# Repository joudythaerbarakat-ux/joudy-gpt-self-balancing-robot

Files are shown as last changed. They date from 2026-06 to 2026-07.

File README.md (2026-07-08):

# Joudy GPT — Self-Balancing Robot with BLE Control Interface

> **Presented at NICE 2026** — 11th National Innovation Competition in Engineering  
> Tishk International University, Erbil, Iraq | Dean's Certificate of Appreciation awarded

Demo

---

## Overview

A two-wheeled self-balancing robot implementing a **Kalman-filtered PID controller** on ESP32, with a custom **Bluetooth web app** for real-time control and a **7-state animated LCD emotion display**.

Built and presented at the National Innovation Competition in Engineering (NICE 2026), Mechatronics Department (MECHAT 4), Tishk International University.

---

## Key Technical Features

- **Kalman Filter + PID** — sensor fusion of MPU6050 accelerometer and gyroscope for stable angle estimation; balance loop running at ~100 Hz
- **Dual operating modes** — RC mode (manual BLE control) and BALANCE mode (autonomous stabilisation with BLE directional trim)
- **Live PID tuning over BLE** — Kp, Ki, Kd, setpoint, and axis configuration adjustable at runtime without re-flashing firmware
- **7-state animated LCD face system** — IDLE (auto-blink), HAPPY, SAD, ANGRY, SURPRISED, TALKING (mouth animation), THINKING (asymmetric eye animation); all BLE-controllable in real time
- **Custom BLE web app** — HTML/CSS/JavaScript using Web Bluetooth API; D-pad control, 3 speed modes, 5 pre-programmed voice lines via browser Web Speech API

---

## Hardware

| Component | Role |
|---|---|
| ESP32 WROOM-32 | Main MCU, BLE host |
| MPU6050 IMU | 6-axis accelerometer + gyroscope |
| L298N Motor Driver | Dual DC motor PWM control |
| DC Geared Motors ×2 | Drive wheels |
| XL4015 Buck Converter | 14.8V → 5V power regulation |
| 4× 18650 Li-ion (14.8V, 4S) | Main power supply |
| LCD 16×2 I²C (0x27) | Animated emotion face display |
| PETG 3D-printed chassis | Custom SolidWorks design |

---

## Wiring Diagram

Wiring Diagram

> ⚠️ Diagram is illustrative. Exact GPIO assignments are defined in `AI_ROBOT.ino` (lines 14–19).  
> Motor pins: IN1=14, IN2=27, ENA=12, IN3=13, IN4=15, ENB=33. I²C: SDA=21, SCL=22.

---

## Software Architecture

```
loop() ~100 Hz
├── handleSerialCommands()     # BLE + Serial command parser
├── balanceUpdate(dt)          # Core balance loop
│   ├── mpuRead()              # Raw IMU register read (I²C)
│   ├── getRawAccelAngle()     # atan2 angle from accel axes
│   ├── getRawGyroRate()       # Gyro rate with axis selection
│   ├── kalman.update()        # Discrete Kalman filter
│   └── motorsDriveRaw()       # L298N PWM output with deadband
└── updateFace()               # LCD state machine @ 10 Hz
```

---

## Control System

Discrete Kalman filter for angle estimation, fusing accelerometer (absolute angle) and gyroscope (rate integration):

| Parameter | Value |
|---|---|
| Process noise Q_angle | 0.001 |
| Process noise Q_bias | 0.003 |
| Measurement noise R_meas | 0.03 |
| Default Kp | 12.0 |
| Default Ki | 0.0 |
| Default Kd | 0.8 |
| Safety tilt cutout | ±35° |
| Integral windup limit | ±80 |
| Target loop rate | ~100 Hz |

---

## BLE Command Reference

| Command | Action |
|---|---|
| `F` / `B` / `L` / `R` / `S` | Move / Stop |
| `MODE:RC` | Manual remote control mode |
| `MODE:BALANCE` | Autonomous self-balance mode |
| `CAL` | Calibrate upright angle (300-sample average) |
| `KP:12.0` / `KI:0.0` / `KD:0.8` | Live PID tuning |
| `SP:0.0` | Adjust balance setpoint angle |
| `AXIS:X` / `AXIS:Y` | Select accelerometer tilt axis |
| `GYRO:X/Y/Z` | Select gyroscope rate axis |
| `INV:0` / `INV:1` | Invert angle sign |
| `MINPWM:80` | Motor deadband compensation |
| `DIAG:1` / `DIAG:0` | Serial diagnostic output |
| `FACE:HAPPY` etc. | Set LCD emotion |
| `SPD:1/2/3` | Set RC speed level |

---

## Repository Structure

```
joudy-gpt-self-balancing-robot/
├── AI_ROBOT.ino          # Main ESP32 firmware
├── web-app/
│   └── index.html        # BLE controller (open in Chrome on Android)
├── docs/
│   ├── demo.gif          # Live demonstration
│   └── wiring-diagram.png
├── cad/                  # SolidWorks chassis files 
└── README.md
```

---

## Build & Flash

**Requirements:**
- Arduino IDE 2.x with ESP32 Arduino Core 3.x
- Libraries: `LiquidCrystal_I2C`, `BLEDevice` (ESP32 built-in)

**Steps:**
1. Open `AI_ROBOT.ino` in Arduino IDE
2. Select board: `ESP32 Dev Module`
3. Flash at 115200 baud
4. Open Serial Monitor → send `HELP` for full command reference
5. Open `web-app/index.html` in **Chrome on Android** → tap Connect

---

## Calibration Procedure

1. Place robot on a flat surface, hold **upright and still**
2. Send `CAL` via BLE or Serial Monitor
3. Robot averages 300 samples over ~1.5 seconds
4. Send `MODE:BALANCE`
5. Trim `SP:` value (e.g. `SP:1.5`) to correct forward/backward lean

---

## Competition

Presented at **NICE 2026** (11th National Innovation Competition in Engineering),  
Mechatronics Department (MECHAT 4), Tishk International University, Erbil, Iraq.  
Theme: *Targeting Smart Sustainable Innovations.*  
**Certificate of Appreciation** awarded by the Dean of Engineering Faculty, TIU.

---

## Author

   **Joudy Thaer Barakat**
   Mechatronics Engineering Student, Tishk International University
   [LinkedIn](https://linkedin.com/in/joudy-barakat) · joudythaerbarakat@gmail.com

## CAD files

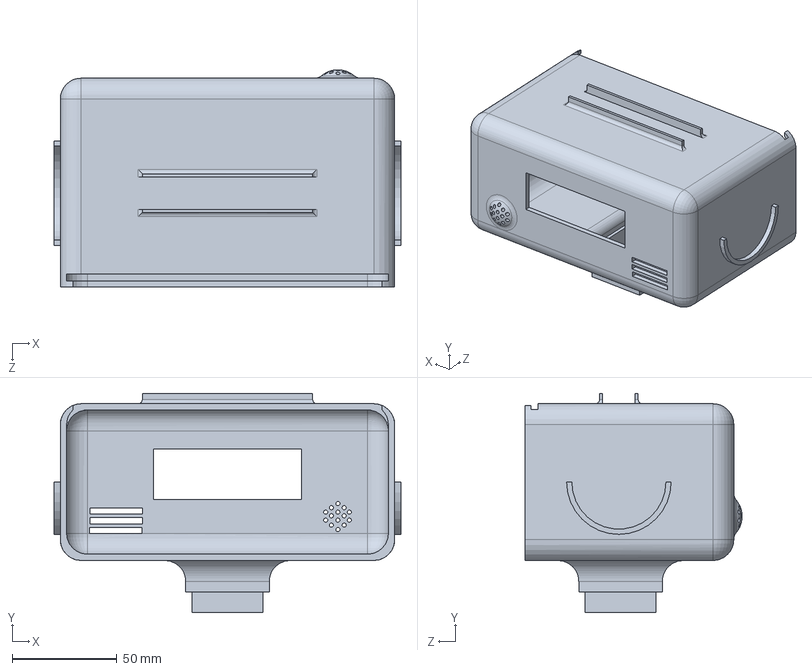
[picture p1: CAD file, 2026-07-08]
cad/head_assembly.SLDPRT
166.0 x 105.0 x 104.0 mm

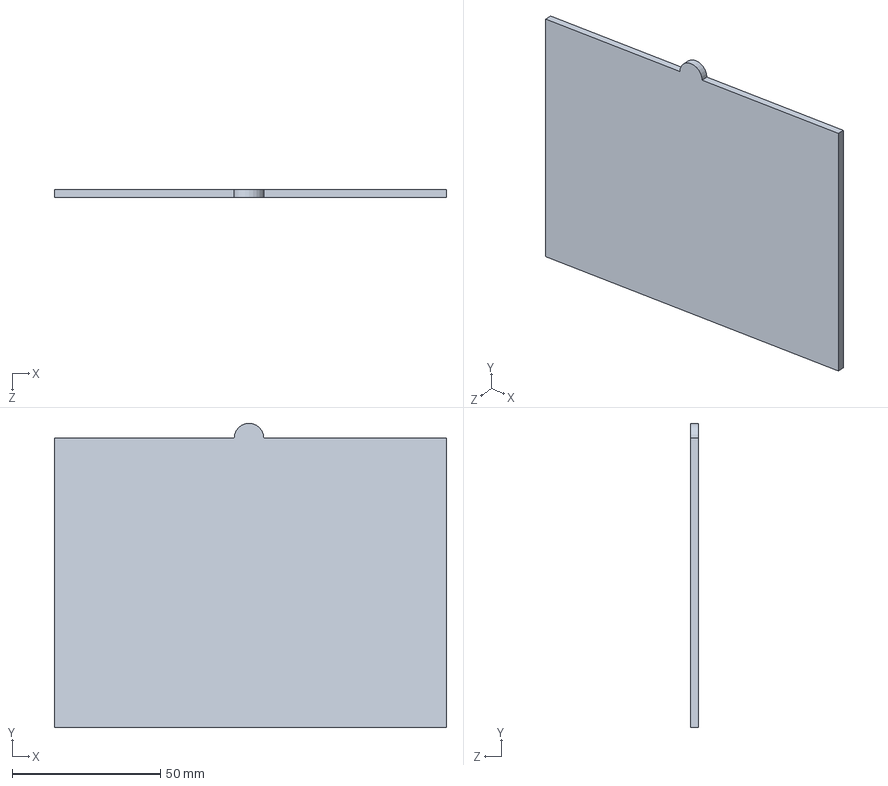
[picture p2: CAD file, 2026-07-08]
cad/door_1.SLDPRT
132.0 x 102.5 x 2.80 mm

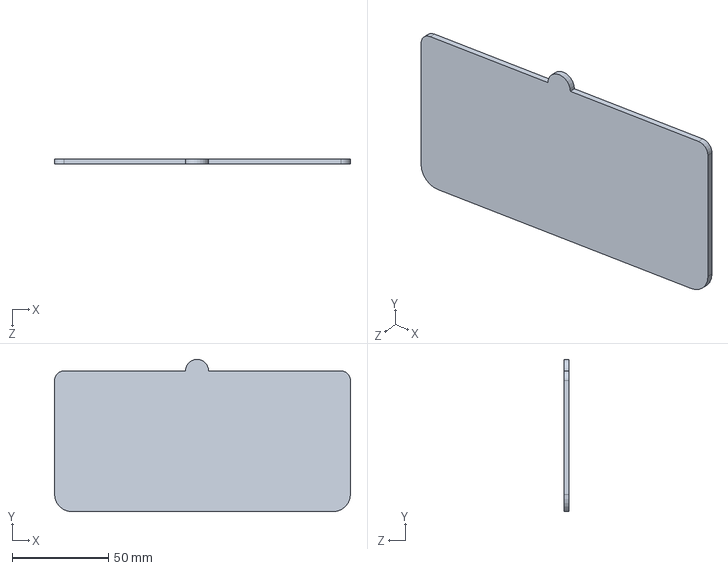
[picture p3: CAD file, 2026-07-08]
cad/door_2.SLDPRT
153.5 x 79.0 x 2.80 mm

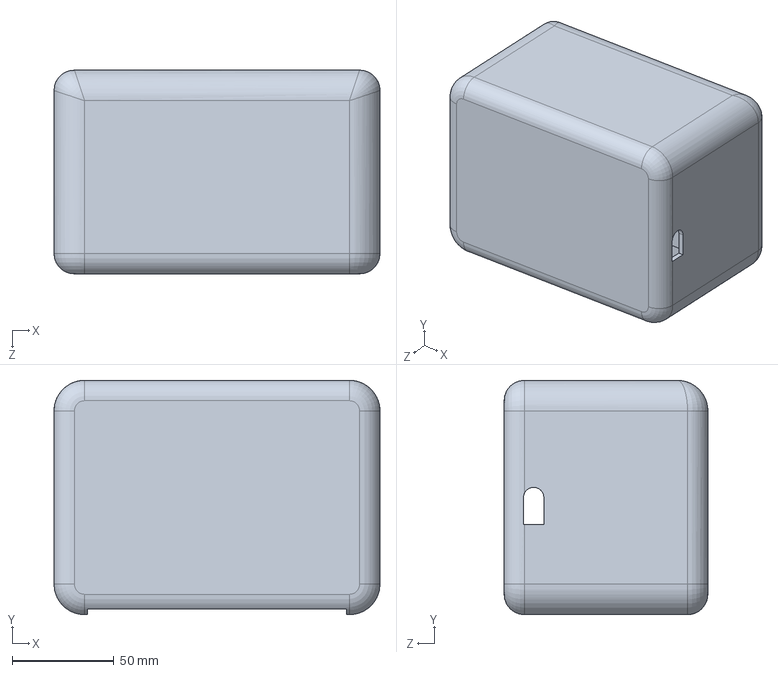
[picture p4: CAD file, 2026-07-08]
cad/chassis_body.SLDPRT
160.0 x 115.0 x 100.0 mm

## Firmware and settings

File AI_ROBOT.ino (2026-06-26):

/*
 * AI_ROBOT — ESP32 BLE/Serial RC + Self-Balance + MPU6050/MPU9250 + LCD Faces
 * ESP32 Arduino Core 3.x compatible
 *
 * Joudy GPT — Self-Balancing Robot
 * Presented at NICE 2026, Tishk International University
 *
 * Runtime tuning via BLE or Serial (no re-upload needed):
 * - MODE:RC / MODE:BALANCE
 * - CAL
 * - AXIS:X / AXIS:Y
 * - GYRO:X / GYRO:Y / GYRO:Z
 * - INV:0 / INV:1
 * - KP:12.0 / KI:0.0 / KD:0.8
 * - SP:0.0
 * - MINPWM:80
 * - DIAG:1 / DIAG:0
 *
 * RC commands: F, B, L, R, S
 * Face commands: FACE:IDLE/HAPPY/SAD/ANGRY/SURPRISED/TALKING/THINKING
 */

#include <Wire.h>
#include <LiquidCrystal_I2C.h>
#include <BLEDevice.h>
#include <BLEServer.h>
#include <BLEUtils.h>
#include <BLE2902.h>

// ─────────────────────────────────────────────────────────────
// BLE UUIDs
// ─────────────────────────────────────────────────────────────
#define SERVICE_UUID  "12345678-1234-1234-1234-123456789abc"
#define CHAR_UUID     "abcdefab-cdef-abcd-efab-cdefabcdefab"

// ─────────────────────────────────────────────────────────────
// MOTOR PINS — L298N
// ─────────────────────────────────────────────────────────────
#define MOTOR_A_IN1  14
#define MOTOR_A_IN2  27
#define MOTOR_A_ENA  12

#define MOTOR_B_IN3  13
#define MOTOR_B_IN4  15
#define MOTOR_B_ENB  33

// ─────────────────────────────────────────────────────────────
// PWM
// ─────────────────────────────────────────────────────────────
#define PWM_FREQ  1000
#define PWM_BITS  8

const uint8_t SPEED_TABLE[3] = {120, 185, 230};
uint8_t currentSpeed = SPEED_TABLE[1];
int MIN_MOTOR_PWM = 80;

// ─────────────────────────────────────────────────────────────
// LCD
// ─────────────────────────────────────────────────────────────
LiquidCrystal_I2C lcd(0x27, 16, 2);

// ─────────────────────────────────────────────────────────────
// MPU
// ─────────────────────────────────────────────────────────────
#define MPU_ADDR 0x68

// ─────────────────────────────────────────────────────────────
// ROBOT MODE
// ─────────────────────────────────────────────────────────────
enum RobotMode { MODE_RC, MODE_BALANCE };
RobotMode robotMode = MODE_RC;

enum TiltAxis { TILT_X, TILT_Y };
enum GyroAxis { GYRO_X, GYRO_Y, GYRO_Z };

TiltAxis tiltAxis = TILT_X;
GyroAxis gyroAxis = GYRO_X;

bool invertAngle   = false;
bool diagnosticMode = true;

// ─────────────────────────────────────────────────────────────
// KALMAN FILTER
// ─────────────────────────────────────────────────────────────
struct Kalman {
  float angle = 0.0f;
  float bias  = 0.0f;
  float P[2][2] = {{1,0},{0,1}};

  const float Q_angle = 0.001f;
  const float Q_bias  = 0.003f;
  const float R_meas  = 0.03f;

  float update(float newAngle, float newRate, float dt) {
    angle += dt * (newRate - bias);
    P[0][0] += dt * (dt*P[1][1] - P[0][1] - P[1][0] + Q_angle);
    P[0][1] -= dt * P[1][1];
    P[1][0] -= dt * P[1][1];
    P[1][1] += Q_bias * dt;

    float S  = P[0][0] + R_meas;
    float K0 = P[0][0] / S;
    float K1 = P[1][0] / S;
    float y  = newAngle - angle;

    angle += K0 * y;
    bias  += K1 * y;

    float P00t = P[0][0], P01t = P[0][1];
    P[0][0] -= K0 * P00t;
    P[0][1] -= K0 * P01t;
    P[1][0] -= K1 * P00t;
    P[1][1] -= K1 * P01t;

    return angle;
  }

  void reset(float startAngle = 0.0f) {
    angle = startAngle; bias = 0.0f;
    P[0][0]=1; P[0][1]=0; P[1][0]=0; P[1][1]=1;
  }
};

Kalman kalman;

// ─────────────────────────────────────────────────────────────
// PID
// ─────────────────────────────────────────────────────────────
float Kp = 12.0f, Ki = 0.0f, Kd = 0.8f;
float angle_setpoint = 0.0f, base_setpoint = 0.0f;
float integral = 0.0f, prev_error = 0.0f;
float accelAngleOffset = 0.0f, gyroOffset = 0.0f;

const float INTEGRAL_LIMIT = 80.0f;
const float TILT_CUTOUT    = 35.0f;

bool calibrated = false;

float balanceDriveTrim = 0.0f;
int   balanceTurnTrim  = 0;

const float BALANCE_FORWARD_SP  =  2.0f;
const float BALANCE_BACKWARD_SP = -2.0f;
const int   BALANCE_TURN_PWM    =  35;

// ─────────────────────────────────────────────────────────────
// DEBUG
// ─────────────────────────────────────────────────────────────
unsigned long lastDebugMs = 0;
const int DEBUG_INTERVAL  = 150;

// ─────────────────────────────────────────────────────────────
// BLE
// ─────────────────────────────────────────────────────────────
bool deviceConnected = false;
BLECharacteristic* pCharacteristic = nullptr;

// ─────────────────────────────────────────────────────────────
// LCD FACE
// ─────────────────────────────────────────────────────────────
enum FaceState { IDLE, HAPPY, SAD, ANGRY, SURPRISED, TALKING, THINKING };
FaceState currentFace = IDLE, pendingFace = IDLE;
bool faceChanged = false;

#define C_EYE_OPEN   0
#define C_EYE_HALF   1
#define C_EYE_SHUT   2
#define C_M_HAPPY    3
#define C_M_SAD      4
#define C_M_TALK     5
#define C_M_FLAT     6
#define C_EYEBROW_UP 7

byte EYES_OPEN[8]    = {0b00000,0b01110,0b11111,0b11011,0b11111,0b01110,0b00000,0b00000};
byte EYES_HALF[8]    = {0b00000,0b00000,0b01110,0b11111,0b11111,0b01110,0b00000,0b00000};
byte EYES_SHUT[8]    = {0b00000,0b00000,0b00000,0b11111,0b00000,0b00000,0b00000,0b00000};
byte MOUTH_HAPPY[8]  = {0b00000,0b00000,0b10001,0b01110,0b00000,0b00000,0b00000,0b00000};
byte MOUTH_SAD[8]    = {0b00000,0b00000,0b01110,0b10001,0b00000,0b00000,0b00000,0b00000};
byte MOUTH_TALK[8]   = {0b00000,0b01110,0b11111,0b01110,0b00000,0b00000,0b00000,0b00000};
byte MOUTH_FLAT[8]   = {0b00000,0b00000,0b11111,0b00000,0b00000,0b00000,0b00000,0b00000};
byte EYEBROW_UP[8]   = {0b11111,0b00000,0b01110,0b11111,0b11011,0b11111,0b01110,0b00000};

struct FaceBuffer { byte left,right,mouth; bool browLeft,browRight; };
FaceBuffer displayedFace = {255,255,255,false,false};

// ─────────────────────────────────────────────────────────────
// FORWARD DECLARATIONS
// ─────────────────────────────────────────────────────────────
void handleCommand(String cmd);
void handleSerialCommands();
void motorsStop();
void motorsDriveRaw(int l, int r);
void motorsDrive(int pwm, bool lf, bool rf);
void motorsTurn(bool spinRight);
bool mpuInit();
void mpuRead(float&,float&,float&,float&,float&,float&);
float getRawAccelAngle(float,float,float);
float getRawGyroRate(float,float,float);
void calibrateMPU();
void balanceUpdate(float dt);
void setupLCDChars();
void lcdClearFace();
void updateFace();
void renderFace(byte,byte,byte,bool,bool);
void notifyText(const String&);

// ─────────────────────────────────────────────────────────────
// BLE CALLBACKS
// ─────────────────────────────────────────────────────────────
class ServerCallbacks : public BLEServerCallbacks {
  void onConnect(BLEServer*)    override { deviceConnected = true;  Serial.println("[BLE] Connected"); }
  void onDisconnect(BLEServer*) override {
    deviceConnected = false; motorsStop();
    robotMode = MODE_RC; balanceDriveTrim = 0; balanceTurnTrim = 0;
    Serial.println("[BLE] Disconnected");
    BLEDevice::startAdvertising();
  }
};

class CharCallbacks : public BLECharacteristicCallbacks {
  void onWrite(BLECharacteristic* c) override {
    String cmd = c->getValue().c_str();
    cmd.trim(); handleCommand(cmd);
  }
};

// ─────────────────────────────────────────────────────────────
// NOTIFY
// ─────────────────────────────────────────────────────────────
void notifyText(const String &msg) {
  Serial.println(msg);
  if (deviceConnected && pCharacteristic) {
    pCharacteristic->setValue(msg.c_str());
    pCharacteristic->notify();
  }
}

// ─────────────────────────────────────────────────────────────
// MPU
// ─────────────────────────────────────────────────────────────
bool mpuInit() {
  Wire.beginTransmission(MPU_ADDR); Wire.write(0x75); Wire.endTransmission(false);
  Wire.requestFrom((uint8_t)MPU_ADDR,(uint8_t)1);
  if (!Wire.available()) { notifyText("[MPU] Not found."); return false; }
  uint8_t w = Wire.read();
  Serial.print("[MPU] WHO_AM_I=0x"); Serial.println(w,HEX);
  Wire.beginTransmission(MPU_ADDR); Wire.write(0x6B); Wire.write(0x00); Wire.endTransmission(true); delay(100);
  Wire.beginTransmission(MPU_ADDR); Wire.write(0x1B); Wire.write(0x00); Wire.endTransmission(true);
  Wire.beginTransmission(MPU_ADDR); Wire.write(0x1C); Wire.write(0x00); Wire.endTransmission(true);
  Wire.beginTransmission(MPU_ADDR); Wire.write(0x1A); Wire.write(0x03); Wire.endTransmission(true);
  notifyText("[MPU] Configured."); return true;
}

void mpuRead(float &ax,float &ay,float &az,float &gx,float &gy,float &gz) {
  Wire.beginTransmission(MPU_ADDR); Wire.write(0x3B); Wire.endTransmission(false);
  Wire.requestFrom((uint8_t)MPU_ADDR,(uint8_t)14,(uint8_t)true);
  if (Wire.available()<14){ax=ay=az=gx=gy=gz=0;return;}
  int16_t AX=(Wire.read()<<8)|Wire.read(), AY=(Wire.read()<<8)|Wire.read(), AZ=(Wire.read()<<8)|Wire.read();
  Wire.read(); Wire.read();
  int16_t GX=(Wire.read()<<8)|Wire.read(), GY=(Wire.read()<<8)|Wire.read(), GZ=(Wire.read()<<8)|Wire.read();
  ax=AX/16384.0f; ay=AY/16384.0f; az=AZ/16384.0f;
  gx=GX/131.0f;   gy=GY/131.0f;   gz=GZ/131.0f;
}

float getRawAccelAngle(float ax,float ay,float az) {
  float a = (tiltAxis==TILT_X) ? atan2f(ax,az)*(180/PI) : atan2f(ay,az)*(180/PI);
  return invertAngle ? -a : a;
}

float getRawGyroRate(float gx,float gy,float gz) {
  float r = (gyroAxis==GYRO_X)?gx:(gyroAxis==GYRO_Y)?gy:gz;
  return invertAngle ? -r : r;
}

// ─────────────────────────────────────────────────────────────
// CALIBRATION
// ─────────────────────────────────────────────────────────────
void calibrateMPU() {
  notifyText("[CAL] Hold upright. Starting in 2s...");
  lcd.clear(); lcd.setCursor(0,0); lcd.print("Hold upright");
  lcd.setCursor(0,1); lcd.print("Cal in 2 sec");
  motorsStop(); delay(2000);
  float angleSum=0, gyroSum=0;
  for(int i=0;i<300;i++){
    float ax,ay,az,gx,gy,gz;
    mpuRead(ax,ay,az,gx,gy,gz);
    angleSum += getRawAccelAngle(ax,ay,az);
    gyroSum  += getRawGyroRate(gx,gy,gz);
    delay(5);
  }
  accelAngleOffset = angleSum/300; gyroOffset = gyroSum/300;
  calibrated = true;
  kalman.reset(0); integral=0; prev_error=0;
  Serial.printf("[CAL] angle_offset=%.3f gyro_offset=%.4f\n",accelAngleOffset,gyroOffset);
  lcd.clear(); lcd.setCursor(0,0); lcd.print("Angle offset:");
  lcd.setCursor(0,1); lcd.print(accelAngleOffset,2); lcd.print(" deg");
  delay(1500); lcdClearFace();
  notifyText("[CAL] Done.");
}

// ─────────────────────────────────────────────────────────────
// MOTORS
// ─────────────────────────────────────────────────────────────
void motorsStop() {
  digitalWrite(MOTOR_A_IN1,HIGH); digitalWrite(MOTOR_A_IN2,HIGH);
  digitalWrite(MOTOR_B_IN3,HIGH); digitalWrite(MOTOR_B_IN4,HIGH);
  ledcWrite(MOTOR_A_ENA,0); ledcWrite(MOTOR_B_ENB,0);
}

void setMotorA(int pwm) {
  pwm=constrain(pwm,-255,255);
  if(!pwm){digitalWrite(MOTOR_A_IN1,HIGH);digitalWrite(MOTOR_A_IN2,HIGH);ledcWrite(MOTOR_A_ENA,0);return;}
  digitalWrite(MOTOR_A_IN1,pwm>0); digitalWrite(MOTOR_A_IN2,pwm<0);
  ledcWrite(MOTOR_A_ENA,abs(pwm));
}

void setMotorB(int pwm) {
  pwm=constrain(pwm,-255,255);
  if(!pwm){digitalWrite(MOTOR_B_IN3,HIGH);digitalWrite(MOTOR_B_IN4,HIGH);ledcWrite(MOTOR_B_ENB,0);return;}
  digitalWrite(MOTOR_B_IN3,pwm>0); digitalWrite(MOTOR_B_IN4,pwm<0);
  ledcWrite(MOTOR_B_ENB,abs(pwm));
}

void motorsDriveRaw(int l,int r) { setMotorA(l); setMotorB(r); }
void motorsDrive(int pwm,bool lf,bool rf) { motorsDriveRaw(lf?pwm:-pwm, rf?pwm:-pwm); }
void motorsTurn(bool right) { motorsDriveRaw(right?currentSpeed:-currentSpeed, right?-currentSpeed:currentSpeed); }

// ─────────────────────────────────────────────────────────────
// BALANCE UPDATE
// ─────────────────────────────────────────────────────────────
void balanceUpdate(float dt) {
  if(robotMode!=MODE_BALANCE||!calibrated) { if(!calibrated) motorsStop(); return; }
  if(dt<=0.001f||dt>0.1f) return;

  float ax,ay,az,gx,gy,gz;
  mpuRead(ax,ay,az,gx,gy,gz);
  float accelAngle = getRawAccelAngle(ax,ay,az)-accelAngleOffset;
  float gyroRate   = getRawGyroRate(gx,gy,gz)-gyroOffset;
  float angle      = kalman.update(accelAngle,gyroRate,dt);

  if(diagnosticMode && millis()-lastDebugMs>=DEBUG_INTERVAL) {
    Serial.printf("angle:%.2f sp:%.2f\n",angle,angle_setpoint);
    lastDebugMs=millis();
  }

  if(fabsf(angle)>TILT_CUTOUT) { motorsStop(); integral=0; prev_error=0; return; }

  angle_setpoint = base_setpoint + balanceDriveTrim;
  float error    = angle_setpoint - angle;
  integral      += error*dt;
  integral       = constrain(integral,-INTEGRAL_LIMIT,INTEGRAL_LIMIT);
  float deriv    = (error-prev_error)/dt;
  prev_error     = error;

  int output = constrain((int)(Kp*error+Ki*integral+Kd*deriv),-255,255);
  int spd    = abs(output);
  if(spd<5) spd=0; else spd=constrain(spd+MIN_MOTOR_PWM,MIN_MOTOR_PWM,255);

  int balPwm = (spd==0)?0:(output>0?spd:-spd);
  motorsDriveRaw(constrain(balPwm+balanceTurnTrim,-255,255),
                 constrain(balPwm-balanceTurnTrim,-255,255));
}

// ─────────────────────────────────────────────────────────────
// COMMAND HANDLER
// ─────────────────────────────────────────────────────────────
void handleCommand(String cmd) {
  cmd.trim(); cmd.toUpperCase(); cmd.replace(" ","");
  if(!cmd.length()) return;
  Serial.print("[CMD] "); Serial.println(cmd);

  if(cmd=="CAL")           { calibrateMPU(); return; }
  if(cmd=="MODE:RC")       { robotMode=MODE_RC; balanceDriveTrim=0; balanceTurnTrim=0; motorsStop(); notifyText("[MODE] RC"); return; }
  if(cmd=="MODE:BALANCE"||cmd=="MODE:BAL") {
    if(!calibrated){notifyText("[MODE] Send CAL first.");return;}
    robotMode=MODE_BALANCE; balanceDriveTrim=0; balanceTurnTrim=0;
    integral=0; prev_error=0; kalman.reset(0); notifyText("[MODE] BALANCE"); return;
  }
  if(cmd=="AXIS:X")  { tiltAxis=TILT_X; calibrated=false; notifyText("[AXIS] X. Send CAL."); return; }
  if(cmd=="AXIS:Y")  { tiltAxis=TILT_Y; calibrated=false; notifyText("[AXIS] Y. Send CAL."); return; }
  if(cmd=="GYRO:X")  { gyroAxis=GYRO_X; calibrated=false; notifyText("[GYRO] X. Send CAL."); return; }
  if(cmd=="GYRO:Y")  { gyroAxis=GYRO_Y; calibrated=false; notifyText("[GYRO] Y. Send CAL."); return; }
  if(cmd=="GYRO:Z")  { gyroAxis=GYRO_Z; calibrated=false; notifyText("[GYRO] Z. Send CAL."); return; }
  if(cmd=="INV:0")   { invertAngle=false; calibrated=false; notifyText("[INV] OFF. Send CAL."); return; }
  if(cmd=="INV:1")   { invertAngle=true;  calibrated=false; notifyText("[INV] ON. Send CAL."); return; }
  if(cmd=="DIAG:0")  { diagnosticMode=false; notifyText("[DIAG] OFF"); return; }
  if(cmd=="DIAG:1")  { diagnosticMode=true;  notifyText("[DIAG] ON");  return; }

  if(cmd.startsWith("KP:"))     { Kp=cmd.substring(3).toFloat(); Serial.print("[PID] Kp="); Serial.println(Kp); return; }
  if(cmd.startsWith("KI:"))     { Ki=cmd.substring(3).toFloat(); integral=0; Serial.print("[PID] Ki="); Serial.println(Ki); return; }
  if(cmd.startsWith("KD:"))     { Kd=cmd.substring(3).toFloat(); Serial.print("[PID] Kd="); Serial.println(Kd); return; }
  if(cmd.startsWith("SP:"))     { base_setpoint=cmd.substring(3).toFloat(); integral=0; prev_error=0; return; }
  if(cmd.startsWith("MINPWM:")) { MIN_MOTOR_PWM=constrain(cmd.substring(7).toInt(),0,180); return; }
  if(cmd=="SPD:1"){ currentSpeed=SPEED_TABLE[0]; return; }
  if(cmd=="SPD:2"){ currentSpeed=SPEED_TABLE[1]; return; }
  if(cmd=="SPD:3"){ currentSpeed=SPEED_TABLE[2]; return; }

  if(cmd=="FACE:IDLE")     { pendingFace=IDLE;      faceChanged=true; return; }
  if(cmd=="FACE:HAPPY")    { pendingFace=HAPPY;     faceChanged=true; return; }
  if(cmd=="FACE:SAD")      { pendingFace=SAD;       faceChanged=true; return; }
  if(cmd=="FACE:ANGRY")    { pendingFace=ANGRY;     faceChanged=true; return; }
  if(cmd=="FACE:SURPRISED"){ pendingFace=SURPRISED; faceChanged=true; return; }
  if(cmd=="FACE:TALKING")  { pendingFace=TALKING;   faceChanged=true; return; }
  if(cmd=="FACE:THINKING") { pendingFace=THINKING;  faceChanged=true; return; }

  // Movement
  if(robotMode==MODE_RC) {
    if(cmd=="F") { motorsDrive(currentSpeed,true,true);   return; }
    if(cmd=="B") { motorsDrive(currentSpeed,false,false); return; }
    if(cmd=="L") { motorsTurn(false); return; }
    if(cmd=="R") { motorsTurn(true);  return; }
    if(cmd=="S") { motorsStop();      return; }
  }
  if(robotMode==MODE_BALANCE) {
    if(cmd=="F") { balanceDriveTrim=BALANCE_FORWARD_SP;  return; }
    if(cmd=="B") { balanceDriveTrim=BALANCE_BACKWARD_SP; return; }
    if(cmd=="L") { balanceTurnTrim=-BALANCE_TURN_PWM;    return; }
    if(cmd=="R") { balanceTurnTrim=BALANCE_TURN_PWM;     return; }
    if(cmd=="S") { balanceDriveTrim=0; balanceTurnTrim=0; return; }
  }
  Serial.println("[CMD] Unknown.");
}

void handleSerialCommands() {
  static String input="";
  while(Serial.available()) {
    char c=Serial.read();
    if(c=='\n'||c=='\r') { if(input.length()) { handleCommand(input); input=""; } }
    else { input+=c; if(input.length()>80) input=""; }
  }
}

// ─────────────────────────────────────────────────────────────
// LCD FACES
// ─────────────────────────────────────────────────────────────
void setupLCDChars() {
  lcd.createChar(C_EYE_OPEN,EYES_OPEN); lcd.createChar(C_EYE_HALF,EYES_HALF);
  lcd.createChar(C_EYE_SHUT,EYES_SHUT); lcd.createChar(C_M_HAPPY,MOUTH_HAPPY);
  lcd.createChar(C_M_SAD,MOUTH_SAD);    lcd.createChar(C_M_TALK,MOUTH_TALK);
  lcd.createChar(C_M_FLAT,MOUTH_FLAT);  lcd.createChar(C_EYEBROW_UP,EYEBROW_UP);
}

void lcdClearFace() { lcd.clear(); displayedFace={255,255,255,false,false}; }

void renderFace(byte l,byte r,byte m,bool bl,bool br) {
  byte fl=bl?C_EYEBROW_UP:l, fr=br?C_EYEBROW_UP:r;
  if(fl!=displayedFace.left||bl!=displayedFace.browLeft)  { lcd.setCursor(3,0);  lcd.write(fl); }
  if(fr!=displayedFace.right||br!=displayedFace.browRight){ lcd.setCursor(12,0); lcd.write(fr); }
  if(m!=displayedFace.mouth)                               { lcd.setCursor(7,1);  lcd.write(m);  }
  displayedFace={fl,fr,m,bl,br};
}

void updateFace() {
  if(faceChanged) { currentFace=pendingFace; faceChanged=false; lcdClearFace(); }
  unsigned long t=millis();
  switch(currentFace) {
    case IDLE:      ((t%3000)<2800)?renderFace(C_EYE_OPEN,C_EYE_OPEN,C_M_FLAT,0,0):renderFace(C_EYE_SHUT,C_EYE_SHUT,C_M_FLAT,0,0); break;
    case HAPPY:     renderFace(C_EYE_OPEN,C_EYE_OPEN,C_M_HAPPY,0,0); break;
    case SAD:       renderFace(C_EYE_HALF,C_EYE_HALF,C_M_SAD,0,0); break;
    case ANGRY:     renderFace(C_EYE_SHUT,C_EYE_SHUT,C_M_SAD,1,1); break;
    case SURPRISED: renderFace(C_EYEBROW_UP,C_EYEBROW_UP,C_M_TALK,1,1); break;
    case TALKING:   ((t/120)%2)?renderFace(C_EYE_OPEN,C_EYE_OPEN,C_M_TALK,0,0):renderFace(C_EYE_OPEN,C_EYE_OPEN,C_M_FLAT,0,0); break;
    case THINKING:  { int p=(t/600)%3;
      if(p==0) renderFace(C_EYE_HALF,C_EYE_OPEN,C_M_FLAT,0,0);
      else if(p==1) renderFace(C_EYE_SHUT,C_EYE_OPEN,C_M_FLAT,0,0);
      else renderFace(C_EYE_HALF,C_EYE_OPEN,C_M_FLAT,1,0); break; }
  }
}

// ─────────────────────────────────────────────────────────────
// SETUP
// ─────────────────────────────────────────────────────────────
void setup() {
  Serial.begin(115200); delay(300);
  Serial.println("[BOOT] AI_ROBOT — Joudy GPT");

  pinMode(MOTOR_A_IN1,OUTPUT); pinMode(MOTOR_A_IN2,OUTPUT);
  pinMode(MOTOR_B_IN3,OUTPUT); pinMode(MOTOR_B_IN4,OUTPUT);
  ledcAttach(MOTOR_A_ENA,PWM_FREQ,PWM_BITS);
  ledcAttach(MOTOR_B_ENB,PWM_FREQ,PWM_BITS);
  motorsStop();

  Wire.begin(21,22); Wire.setClock(400000);
  lcd.init(); lcd.backlight(); setupLCDChars(); lcdClearFace();
  lcd.setCursor(0,0); lcd.print("JOUDY GPT"); lcd.setCursor(0,1); lcd.print("Booting...");

  bool mpuOk = mpuInit();
  lcd.clear();
  if(!mpuOk) { lcd.print("MPU ERROR"); lcd.setCursor(0,1); lcd.print("RC only"); }
  else        { lcd.print("MPU Ready"); lcd.setCursor(0,1); lcd.print("Send CAL"); }
  delay(1000); lcdClearFace();

  BLEDevice::init("AI_ROBOT");
  BLEServer* pServer = BLEDevice::createServer();
  pServer->setCallbacks(new ServerCallbacks());
  BLEService* pService = pServer->createService(SERVICE_UUID);
  pCharacteristic = pService->createCharacteristic(CHAR_UUID,
    BLECharacteristic::PROPERTY_READ|BLECharacteristic::PROPERTY_WRITE|BLECharacteristic::PROPERTY_NOTIFY);
  pCharacteristic->addDescriptor(new BLE2902());
  pCharacteristic->setCallbacks(new CharCallbacks());
  pCharacteristic->setValue("READY");
  pService->start();
  BLEDevice::getAdvertising()->addServiceUUID(SERVICE_UUID);
  BLEDevice::getAdvertising()->setScanResponse(true);
  BLEDevice::startAdvertising();

  Serial.println("[BOOT] Advertising as AI_ROBOT. Send HELP.");
}

// ─────────────────────────────────────────────────────────────
// LOOP
// ─────────────────────────────────────────────────────────────
void loop() {
  static unsigned long lastUs=micros(), lastFaceMs=0;
  unsigned long nowUs=micros();
  float dt=(nowUs-lastUs)*1e-6f;
  lastUs=nowUs;

  handleSerialCommands();
  balanceUpdate(dt);

  unsigned long nowMs=millis();
  if(nowMs-lastFaceMs>=100) { lastFaceMs=nowMs; updateFace(); }

  long el=(long)(micros()-nowUs);
  if(el<10000) delayMicroseconds(10000-el);
}

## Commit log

2026-07-08 Create cad
2026-07-08 Add SolidWorks chassis files
    [BODY final final.SLDPRT, door 1.SLDPRT, door2.SLDPRT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]
2026-07-08 Remove placeholder cad file
2026-07-08 Rename BODY final final.SLDPRT to cad/chassis_body.SLDPRT
    [chassis_body.SLDPRT]
2026-07-08 Rename door 1.SLDPRT to cad/door_1.SLDPRT
    [door_1.SLDPRT]
2026-07-08 Rename head final.SLDPRT to cad/head_assembly.SLDPRT
    [head_assembly.SLDPRT]
